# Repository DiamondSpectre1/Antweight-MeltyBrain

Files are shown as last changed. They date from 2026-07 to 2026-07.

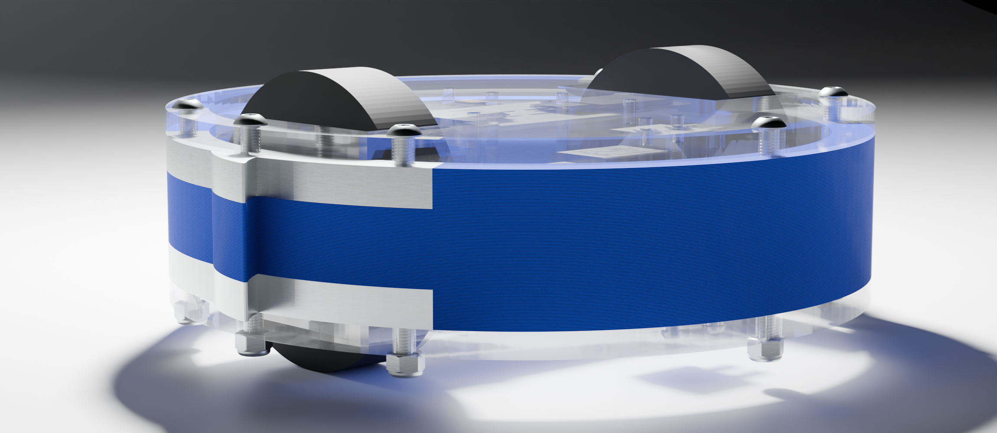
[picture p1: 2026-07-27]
BattleBot.png

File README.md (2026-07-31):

# Antweight-MeltyBrain
An antweight (1lb) battlebot following the melty brain style. Spins up using two N20 motors attached to foam wheels on a polycarb/PETG sandwich chassis. 

Drives in any configuration and utilizes AR500 Steel Blades

Includes a lightweight configuration where two blades are removed and the remaining two are shifted to the vertical-middle of the robot.

Uses FS2A FlySky Transmitter-Receiver system, H3LIS331 Accelerometer from Adafruit, Adafruit Itsybitsy as the processor, Heading Light for visual feedback and control, and 3S Lipo Battery for power.

CAD at: https://cad.onshape.com/documents/249e984842615adfc8b8828b/w/c7db2f86ab7ab3ec7a08f806/e/15440b52b40955b3f96315d0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

BOM/Cart: https://docs.google.com/spreadsheets/d/1nNTRbGGS_KuisO4c58RzzcGgVzOWWuhgAdikpHYEQr4/edit?usp=sharing

Normal Configuration:
BattleBot

Lightweight Configuration (two blades removed):


Assembly Instructions:\
Start with a polycarb cap/base piece, both are identical.\
Bolt the 3D printed motor bracket spacer and motor brackets with N20 motors in them to the polycarb base plate using M2 Nuts and Bolts.\
Attach the thick half of the FingerTech twist hubs to each shaft, and bolt down the rod to clamp them to the shafts.\
Bolt the accelerometer and power switch directly to the polycarb using M2 nuts and bolts, make sure the power switch's bolt input is facing the wall of the bot, that way a hole can be drilled for easy access later.\
VHB tape the rest of the electrical components as securely to the base as possible. The Itsy Bitsy, tinyESCs, and receiver should be as close to the center as possible without interfering with the motors or wheels, while the heading beacon can be attached far from the center.\
Slide the foam Fingertech wheels onto the hubs and twist the second, thinner half of the Twist Hubs to lock the wheel in place. \
(Optional) Silicone/other grip tape applied to the wheels for better traction.\
After this, line up the blades and 3D printed body on top of the polycarb, and finally top it off with the other polycarb plate, sandwiching them all with the M3 Nuts and Bolts.\
To access the electronics, simply loosen the M3 Nut and Bolt stack and take off the top polycarb cover.

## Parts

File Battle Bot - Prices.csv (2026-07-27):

Total Cost | Item | Cost/Unit | Quantity | Supplier | Notes | Shipping/Additional | Tax | Link (if applicable)
11.16 | 35 mm M2 | 11.16 | 1 | Mcmaster Carr | Pack of 10 | 0.3 |  | https://www.mcmaster.com/91239A128/
1.33 | M3 Thin Nut | 1.33 | 1 | Aliexpress | Pack of 25 |  |  | https://www.aliexpress.com/ssr/300000512/BundleDeals2?productIds=32798773566%3A12000015834876025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
0.33 | 16 mm M2 | 0.33 | 1 | Aliexpress | Pack of 10 |  |  | https://www.mcmaster.com/91239A711/
11.69 | 3S Lipo Battery | 11.69 | 1 | PalmBeach Bots |  |  |  | https://palmbeachbots.com/products/palm-power-3s-100mah-45c-lipo-battery
24.95 | Accelerometer | 24.95 | 1 | Adafruit |  |  |  | https://www.adafruit.com/product/4627
9.95 | Itsybitsy | 9.95 | 1 | Adafruit |  |  |  | https://www.adafruit.com/product/3677
4.7 | tinyESC v3 | 2.35 | 2 | Aliexpress |  |  |  | https://www.aliexpress.us/item/3256812374332881.html?curPageLogUid=1q2AoJT2WAto
13 | FS2A Receiver | 13 | 1 | Just Cuz Robotics |  |  |  | https://justcuzrobotics.com/products/fs2a-rx
2.95 | 3W Led | 2.95 | 1 | Adafruit |  |  |  | https://www.adafruit.com/product/2530
3.46 | Foam Wheels | 3.46 | 1 | Fingertech | 2x0.5, comes in pair |  |  | https://www.fingertechrobotics.com/proddetail.php?prod=ft-foam-wheels
19.92 | Twist Hubs | 19.92 | 1 | Fingertech | Comes in Pair |  |  | https://www.fingertechrobotics.com/proddetail.php?prod=ft-twist-hubs
1.98 | N20 Motors | 0.99 | 2 | 4 |  |  |  | https://www.aliexpress.us/item/3256803908995996.html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
51.18 | Machined Parts | 51.18 | 1 | SendCutSend |  | Free | 5.27 | https://app.sendcutsend.com/customer#/cart
0
0
0
0
0
0
0
0
 | Grand Total (USD): | 162.17

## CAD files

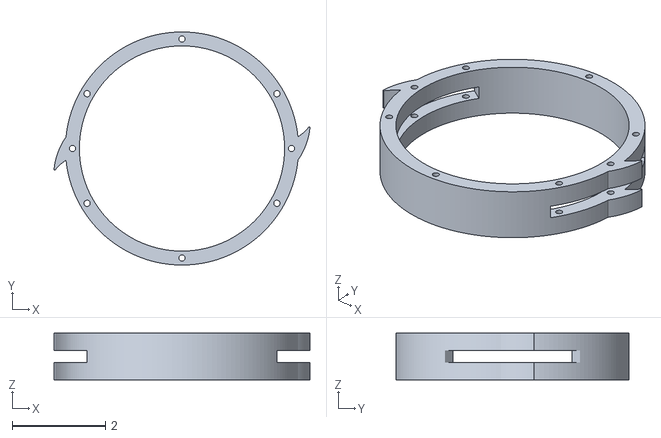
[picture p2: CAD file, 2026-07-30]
Lightweight Configuration Body PETG.stl
5.49 x 5.00 x 1.00

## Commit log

2026-07-31 Rename Assembly - Base.step to CAD Files/Base
2026-07-31 Rename Assembly - Part 1.step to CAD Files/Wheel
2026-07-31 Rename Assembly - Spacer.step to CAD Files/Spacer
2026-07-31 Rename Assembly - blade.step to CAD Files/Blade
2026-07-31 Rename Assembly - body.step to CAD Files/Body
2026-07-31 Rename Wheels - for printing TPU if needed.stl to Production Files/For Printing TPU if Needed
2026-07-31 Rename AR500 steel blade.stl to Production Files/AR500 Steel Blade
2026-07-31 Rename Motor PETG Spacer.stl to Production Files/Motor Spacer
2026-07-31 Rename PETG Main Body.stl to Production Files/PETG Main Body
2026-07-31 Rename Polycarb Base and Cap.stl to Production Files/Polycarb Base and Cap
